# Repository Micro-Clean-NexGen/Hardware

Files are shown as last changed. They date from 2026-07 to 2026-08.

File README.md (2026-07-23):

## Hardware
This document describes the hardware architecture and operating principles of our robot's Mobility and Autonomous Navigation subsystem — the first subsystem being developed for the MVP. It covers locomotion, real-time localization, and obstacle detection and avoidance.

The Steam Cleaning, Air Treatment, along with the full Power Management and Electrical Architecture, will be documented later as development on those areas proceeds. This document follows the same format so all subsystem documents remain consistent and easy to compare.

This documentation covers: electrical wiring, power distribution, computing, sensors, motor control, the bill of materials, and safety notes.

Hardware documentation for the Autonomous Steam Cleaning & Air Sterilization Robot: electrical wiring, power distribution, computing, sensors, motor control, the bill of materials, and safety notes.

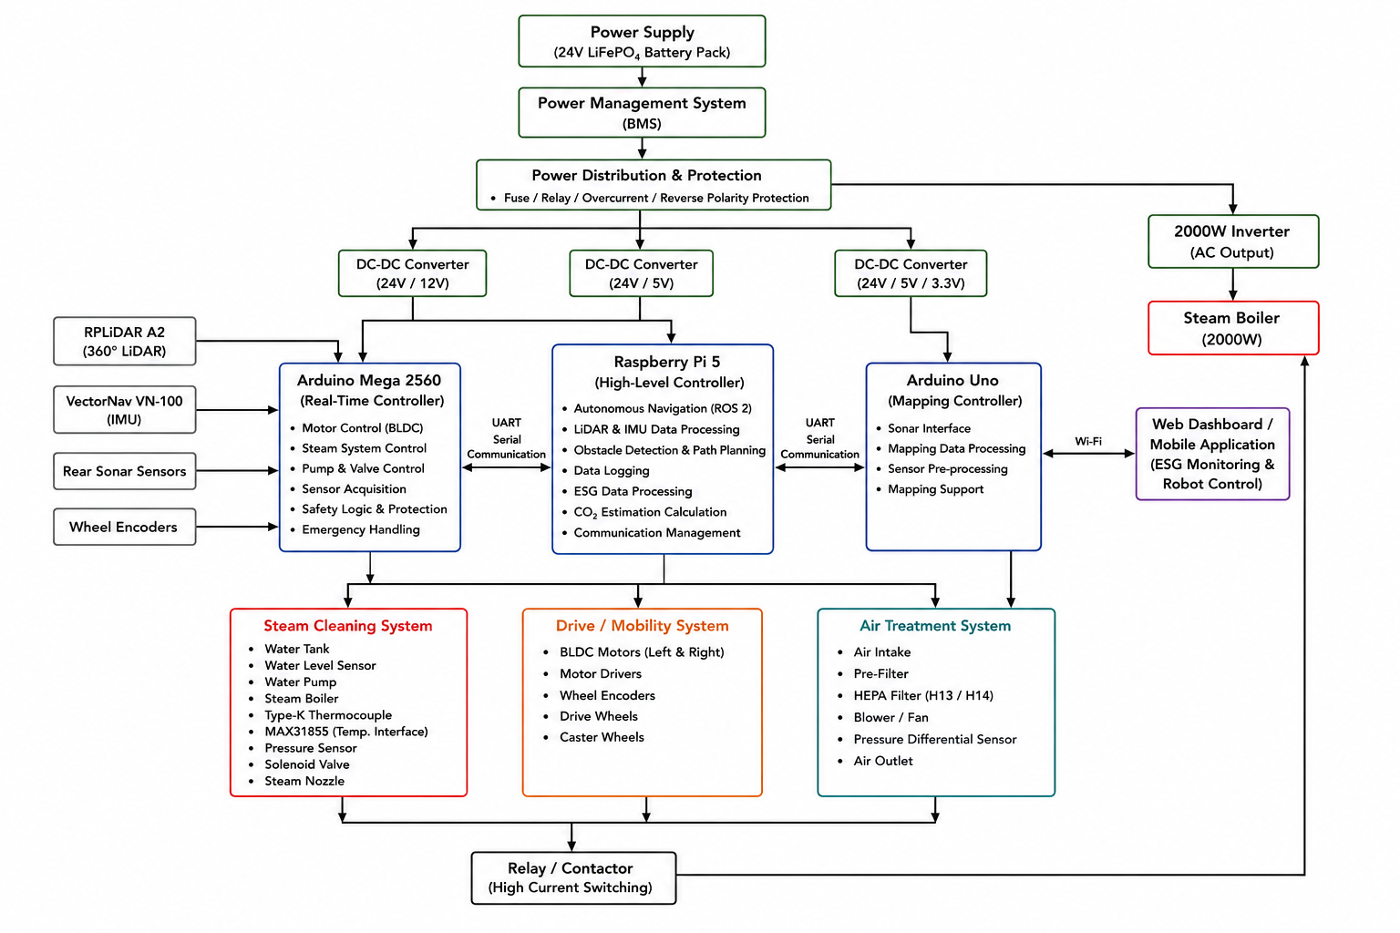
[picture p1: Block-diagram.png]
Block diagram of whole system


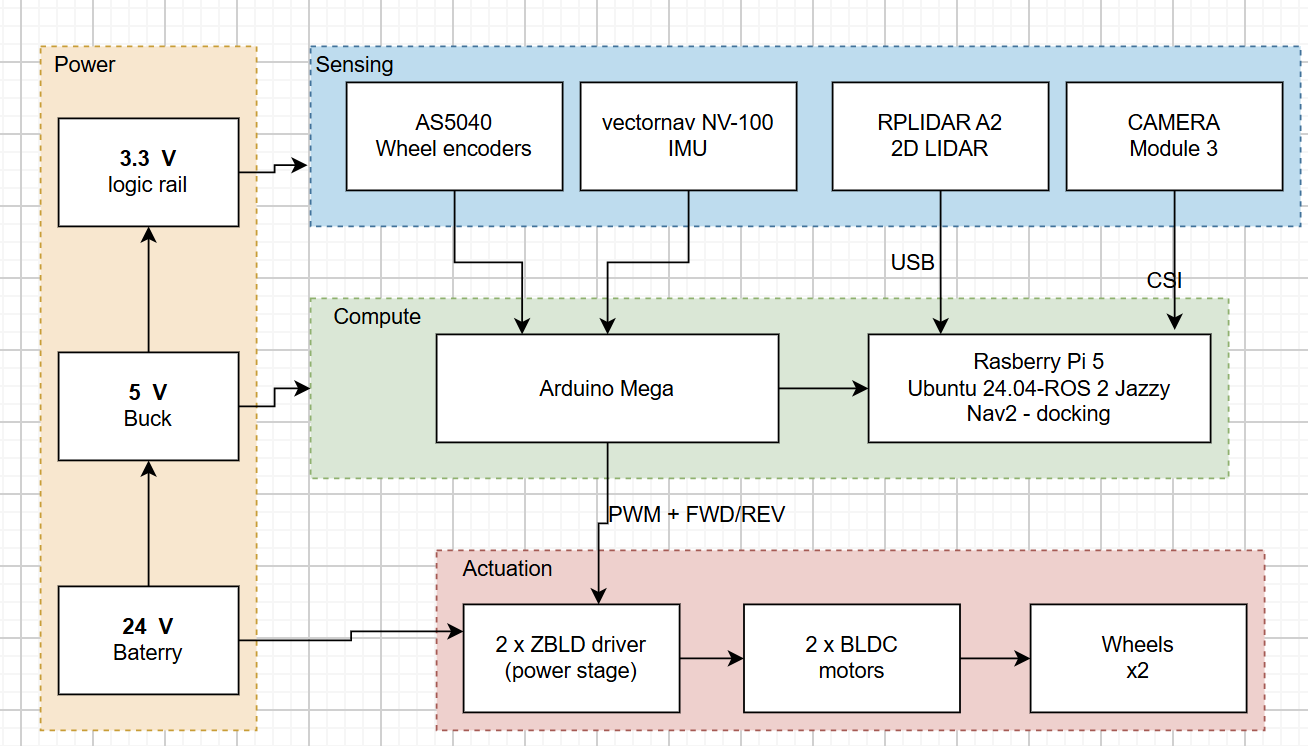
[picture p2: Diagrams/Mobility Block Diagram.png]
Block diagram of mobilty system


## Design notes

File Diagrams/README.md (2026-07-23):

## **Diagram folder used inside hardware repository**

**Battery and Charging space**
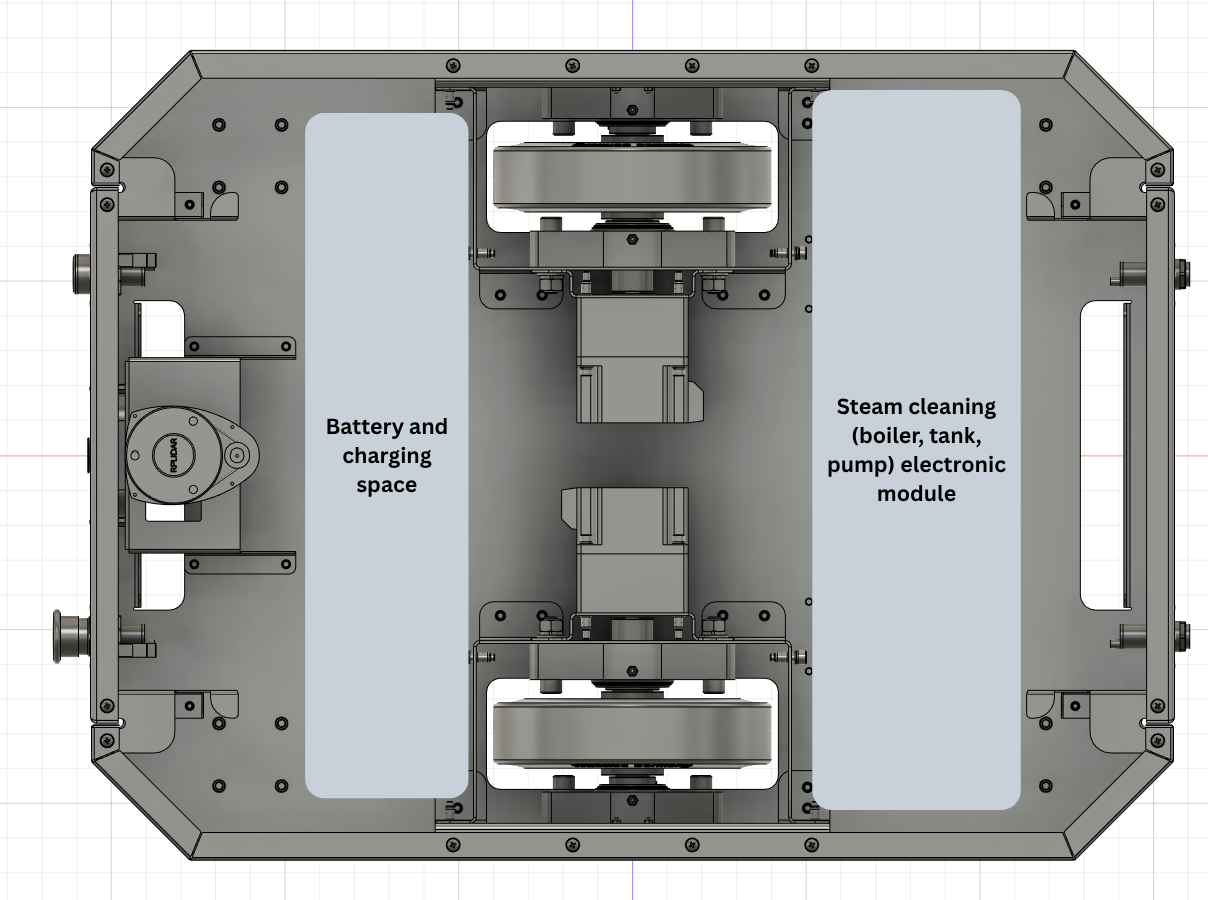
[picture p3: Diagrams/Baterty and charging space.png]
Battery and Charging Space


**Mobiltiy Block diagram**
Mobility Block Diagram

**Mobility Full Assembly**
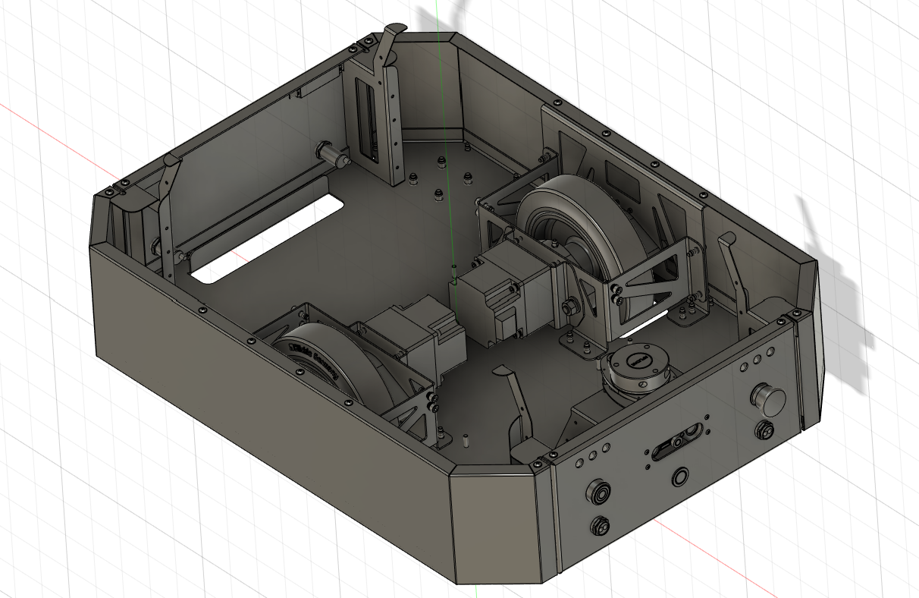
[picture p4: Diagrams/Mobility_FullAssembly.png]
Mobility Full Assembly


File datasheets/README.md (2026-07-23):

# Datasheets

Manufacturer datasheets and manuals for the components used on (or offered as options for) the
Autonomous Steam Cleaning & Air Sterilization Robot **base**. 

> ⚠️ **Third-party documents — copyright of their respective manufacturers.** These PDFs are
> **re-hosted for convenience** with attribution to the source (see each folder). They are **not**
> covered by this repository's licence; all rights remain with the manufacturers.

## What applies to the base build vs. what is optional

The base of the robot documented in this repo uses the **ZD** motor + driver. The **ZLTech** and
**TZBot** parts are **alternative / optional** components for larger product configurations
(higher-power drives, wireless charging, lift, larger battery) — they are **not** on the base build as in the current version for MVP.

| Component | On the base build? |
|---|---|
| ZD BLDC motor (Z4BLD60-24GN-30S) + **ZBLD.C20-120L2R** driver | ✅ **yes — this is the base** |
| ZLAC8015D / ZLAC8030L industrial drivers (CANopen/RS485) | ⚙️ option (higher-power variant) |
|  ZLLG80 hub-motor wheel | ⚙️ option (alternative drivetrain) |
| 24 V 20 Ah battery + BMS (serial protocol) | ⚙️ option (product battery/BMS) |
| WCM-300 wireless charger | ⚙️ option (auto-docking charge) |
| Lift reducer (TZDSXZ-48-400) | ⚙️ option (lift attachment) |

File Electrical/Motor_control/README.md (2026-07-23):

# Motors & drivers (BLDC + ZBLD)

*Last updated: 2026-07-22.*

## Overview
Two **BLDC** (brushless) motors, one per wheel, each driven by its own **ZBLD** driver. The Teensy
sends low-current logic signals to the drivers; the drivers deliver the 24 V power to the motor phases.

- **Motors**: **ZD Z4BLD60-24GN-30S** ×2 — 3-phase BLDC, 24 V, **60 W**, **P=5 (5 pole pairs, on the
  nameplate)**, **3000 rpm** motor + **1:25 spur gearbox** (4GN 25K) → **120 rpm** wheel, rated **3.8 A**.
  U/V/W + Hall. (LEFT=M1, RIGHT=M2) See the [sizing calculations](../../datasheets/motor-sizing-calculations.md).
- **Drivers**: **ZBLD.C20-120L2R** ×2 (24 V, 7.5 A, 120 W). Full specs + datasheets:
   **Red LED / fault blink codes:**
  [motor-driver-fault-codes.md](motor-driver-fault-codes.md).
- ⚠️ **Pole pairs = 5** → verify the driver **DIP SW4/SW5** are set to 5 pole pairs (read the silkscreen
  table on the driver). A wrong pole-pair setting throws off the driver's closed-loop speed scaling.

## Manufacturer reference diagram

The driver's full terminal layout, DIP-switch table, and LED status codes, from the manufacturer:

![ZBLD.C20-120L2R driver setup: 24 V DC+/DC- (fused), motor phases U/V/W + Hall sensors, control inputs FWD/DI1, REV/DI2, JOG/DI3, CLR/DI4, BRK/DI5, COM, VAR/AI2, +5V, ERR/DO1, SPD/DO2, RS485 A/B, the SW1-SW6 DIP-switch configuration table, and the LED status/fault codes]()

*Source: ZD **ZBLD.C20-120L2R** product manual (manufacturer reference figure). This robot wires only a
subset of these terminals and uses a specific DIP configuration — both are detailed below.*

## Communication (Teensy → driver)

The motor-control signal chain is shown below.

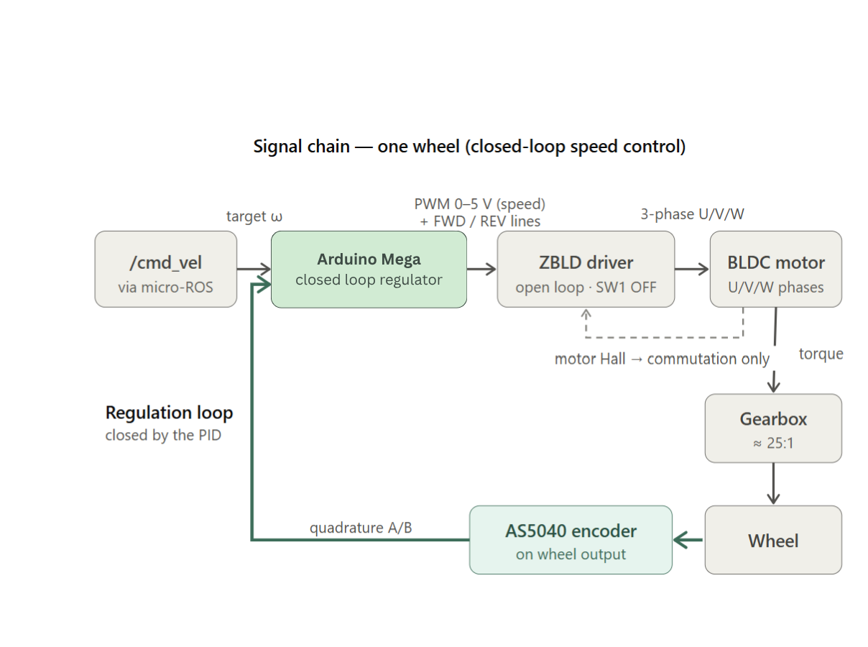
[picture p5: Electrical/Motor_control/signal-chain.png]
Figure — per-wheel signal chain: /cmd_vel → Teensy PID (closed loop) → ZBLD driver (open loop) → BLDC → 25:1 gearbox → wheel → AS5040 encoder back to the PID


Per motor, 3 logic lines from the Teensy:

| Arduino signal | Driver input | Meaning | Left pin | Right pin |
|---|---|---|---|---|
| PWM | `VAR / AI2` | speed setpoint — Teensy PWM @ **3 kHz** on this robot (driver capability: PWM 0–20 kHz, or analog 0–5 V) | **1** | **5** |
| IN_A | `FWD / DI1` | forward direction | **20** | **6** |
| IN_B | `REV / DI2` | reverse direction | **21** | **8** |
| GND | `COM` | **common ground (mandatory)** | GND | GND |

- Power side: `DC+ / DC− = 24 V` (with a fuse). Motor side: phases U/V/W + Hall.
- ⚠️ The driver `COM` **must** be tied to the Teensy GND, otherwise signals/encoders are noisy.

Of the driver's twelve control terminals, this robot wires only **four** — the connections are shown below:

Driver terminal wiring: only DI1 (FWD), DI2 (REV), COM (GND), and AI2 (VAR/PWM speed setpoint) go to the Teensy; DC+/DC- take the fused 24 V and U/V/W + Hall go to the motor

## Driver configuration — DIP switches (SW1–SW6)
Both drivers must be set **identically**. Functions read from the driver silkscreen (2026-06-19):

| Switch | Function | What it does | Was (pre 06-19) | **Now (applied 06-19)** |
|---|---|---|---|---|
| **SW1** | open / closed loop | ON = driver regulates speed itself from the Halls; OFF = driver is just a power stage (Teensy regulates) | ON | **OFF** |
| **SW2** | speed source (`AI1/AI2`) | OFF = internal VAR knob; ON = external 0–5 V on `VAR/AI2` (our Teensy PWM) | ON | ON |
| **SW3** | secondary (direction/internal) | no effect here (direction is driven by FWD/REV pins) | OFF | OFF |
| **SW4 / SW5** | **motor pole pairs** | tells the driver the pole-pair count (2/3/4/5) to convert Hall freq → RPM. **Only used in closed loop** | OFF/OFF (= 2 pp ⚠️) | **ON/ON (= 5 pp)** |
| **SW6** | RS485 termination | bus end resistor; not used (no RS485) | OFF | OFF |

> 🔶 **Pole-pair mismatch found & corrected (2026-06-19):** the motor is **P=5** (5 pole pairs, on the
> nameplate) but SW4/SW5 were OFF/OFF (= 2 pole pairs). Now set to **ON/ON (= 5 pp)**. (Only matters in
> closed loop; harmless but correct in the current open-loop config.)

### Which controller is best — driver vs Teensy PID?
The **Teensy PID is the better controller for this robot** and should be the authoritative one:
- it reads the **AS5040 encoder (1024 cnt/rev)** → fine resolution, and measures the **wheel** speed
  (post-gearbox) — the variable we actually care about (motion + odometry);
- it is **fully tunable** (K_P/K_I/K_D, already tuned to ±2 %), and feeds ROS `/odom`.
- the driver's loop measures the **motor shaft** (pre-gearbox) with **coarse Hall** sensors, is **opaque**
  (only VAR/ACC pots), and needs correct pole pairs.

→ **Run the driver open-loop (SW1=OFF)** so the Teensy is the sole regulator (removes the double-loop that
worsens snaking; makes pole pairs irrelevant). **Plan B** if low-speed cogging appears: go back to closed
loop (SW1=ON) **with SW4/SW5=ON/ON (5 pp)** for a proper cascade (fast driver inner loop + Teensy outer).
The only edge the driver loop has: at low *wheel* speed the motor shaft still spins ~30× faster → richer
Hall signal → potentially smoother very-low-speed than the 50 Hz Teensy loop.

**Config applied 2026-06-19 (both drivers):** `SW1 OFF · SW2 ON · SW3 OFF · SW4 ON · SW5 ON · SW6 OFF`.
(Was SW1 ON, SW2 ON, rest OFF.) **Validated** over 3 motor runs — see
the `openamr-platform-sw` troubleshooting doc (`docs/troubleshooting/diagnostics.md` in that repo).

> ⚠️ **VAR pot is inert in this config**: with SW2=ON the speed comes from AI2 (the PWM), not the VAR/AI1
> pot, so turning VAR does **not** balance the wheels (confirmed: no change across runs). The residual
> ~9 % open-loop L/R asymmetry (right faster) is corrected by the **Teensy PID** (→ ~0.2 % in closed loop).

## Driver configuration — TWO trim pots (CRITICAL)
Each driver has **two** potentiometers. **They must match between LEFT and RIGHT** (calibrate the right
to the left, the known-good reference).

> ⚠️ **Read this alongside the config state.** The VAR **gain** effect below (and the "runaway" root cause)
> applies when **VAR is in the speed path** — i.e. the *original* config (VAR/AI1 selected, or an AI2 gain
> that scales the PWM). In the **current config (SW1=OFF open loop, SW2=ON → AI2)** the **speed comes from
> the PWM on AI2, so the VAR pot is inert for balancing** (see the note above) — the values below are the
> setting to leave it at, not a live balancing knob. ACC/DEC still ramps in either config.

| Pot | Location | Function | Correct setting | Symptom if wrong (when VAR is in the speed path) |
|---|---|---|---|---|
| **VAR** | top | speed / gain (PWM → speed) | ~3.5/10, **same** both sides | too high → wheel runs ~8× too fast → **runaway** |
| **ACC/DEC** | near the DIP switches | acceleration/deceleration ramp | **4/10**, same both sides | =0 → no smoothing → **jerks/oscillation** in closed loop |

See the full story in the `openamr-platform-sw` troubleshooting doc (`docs/troubleshooting/diagnostics.md` in that repo).

## Low-speed behaviour — measured velocity floors (2026-07-02)
Closed-loop sweep **on the ground / under load** (`/cmd_vel` with the PID + dither, as in docking),
real velocity read on `/odom/unfiltered`:

| Axis | Stall | Judder | **Reliable floor** | Clean |
|---|---|---|---|---|
| **Linear** | ≤ 0.02 m/s | 0.03 (min 0, std 0.018) | **0.04 m/s** (min 0.020) | **0.05 m/s** (std 0.004); 0.06–0.10 perfect |
| **Angular** | ≤ 0.08 rad/s | 0.10–0.12 (min 0, high std) | **0.15 rad/s** (min 0.093) | 0.20–0.30 perfect |

> ✅ **The motor is WELL-SIZED (over-sized on torque).** Above the floors the real/commanded ratio is
> **~1.0** → no torque shortfall. The floors are **stick-slip (static friction) + coarse Hall commutation
> at low RPM** (an *operating-point* limit, not a sizing one). Reference: the Z4BLD60-24GN-30S + **1:25**
> gearbox gives a mechanical no-load max of ~**1.26 m/s** (software-capped to ~0.71 m/s) and ~**3.48 N·m/wheel**

**Consequence:** keep commanded velocities **above the floors**. Docking applies this (drive taper floored
at 0.05 m/s, scan rotation 0.17 rad/s, a `min_turn_omega` of 0.15 rad/s with a small deadband so
sub-floor yaw corrections are snapped up or zeroed rather than stalling). Judder on each start-from-standstill
is the static-friction breakaway; a taper (or the driver ACC/DEC ramp) mitigates it.

## Good to know / gotchas
- The original fault ("right wheel runs away, robot doesn't go straight") was **100 % driver tuning**, in
  the **original config where VAR was in the speed path**: the right VAR pot was at max (10) and its
  ACC/DEC pot at 0. After matching both pots to the left, the right wheel tracked correctly. *(Separately,
  during open-loop balancing on 2026-06-19, raising the right VAR made the right wheel speed up to match a
  faster left — same knob, opposite direction, because it was a different starting point.)*
- ⚠️ In the **current config (SW2=ON, AI2 source)** VAR no longer balances the wheels — the residual L/R
  asymmetry is handled entirely by the **Teensy PID** (the right channel needs slightly more PWM for the
  same speed; the PID compensates → ~0.2 % in closed loop). Do not chase balance with the VAR pot here.
- Test the motors safely with the **open-loop mode** (`/debug/openloop`) which bypasses the PID — useful
  to compare the two channels at identical PWM. See the `openamr-platform-fw` debug-telemetry doc (`docs/architecture/debug-telemetry.md`).
- **Always**: wheels off the ground, 24 V on, a hand on the 24 V cut-off for the first tests.

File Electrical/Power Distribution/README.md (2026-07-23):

# Power & electrical safety

*Last updated: 2026-07-23.*

## 🔋 Battery state of charge — THRESHOLDS — READ BEFORE ANY NAV TEST
The design takes **any 24 V battery** . The at-rest thresholds below are for the
**reference build's pack** 
(LiFePO4 / Li-ion rest at different voltages and have flatter discharge curves). **At-rest** voltage
(no load):

| At-rest voltage | State | For navigation |
|---|---|---|
| **~25.5–26 V** | full charge | ✅ OK to test |
| **~24.5 V** | ~70 % | ✅ acceptable |
| **~24 V** | ~50 % | ⚠️ marginal |
| **≤ 23.5 V** | discharged (~30 %) | ❌ **DO NOT test nav** |

⚠️ This is the **at-rest** voltage: **under load (motors) it drops further** (often −1 to −2 V at peaks,
since the pack sags). Below ~22 V under load → drivers undervoltage (ZBLD **fault code 10**, see
[motor-driver-fault-codes.md](../motor_control/motor-driver-fault-codes.md)) → **weak torque + left wheel
(loose contact) drops out → the robot does not follow the plan → it hits obstacles that nav was actually
avoiding.** **RULE: aim for ≥ 25 V at rest before any navigation/avoidance test.** Otherwise we debug Nav2
for nothing (already happened: the real problem was the 24 V, not nav).

**Reading 2026-06-20 (end of session)**: battery at **23.4 V at rest → too low**. Every avoidance test
from this session is inconclusive until the battery is recharged (~25.5 V). To be resumed after charging.

The power distribution is shown in the diagram below.

Figure — power distribution: 230 V charger, 24 V battery (with the missing fuse and disconnect), 24 V drivers, and the buck-derived 5 V/3.3 V logic

## Power architecture — VERIFIED 2026-06-19
```
Battery 24V ──┐
              ├──(parallel)──► V+ / V−  of BOTH drivers   (brown = V+, blue = V−)
Mains 24V  ───┘
              └──(parallel)──► DC-DC 24V→5V ──► Raspberry Pi ──USB──► Teensy ──► IMU + encoders (3.3V)
```
| Element | Supply |
|---|---|
| Motors / drivers | **24 V DC** on `V+ / V−` of each driver. Wire colors: **brown = V+, blue = V−** (confirmed) |
| 24 V source | a **24 V battery pack** (any chemistry) **or** an **AC/DC converter** (230 V mains) — wired **in parallel** to the same 24 V bus |
| Raspberry Pi | **DC-DC 24 V→5 V** buck from the 24 V bus |
| Teensy | powered over **USB** from the Pi (5 V) |
| **IMU + encoders** | **3.3 V from the Teensy** (3.3 V rail). The encoders were originally on the 5 V (VUSB) pin → ~4 V on the Teensy inputs → moved to 3.3 V on 2026-06-19; see ⚠️ encoder overvoltage in [encoders.md](../sensors/encoders.md). The IMU has always been on 3.3 V. |
| LiDAR | powered over its USB (CP2102 adapter) from the Pi |

## 🔴 Safety gaps found (2026-06-19) — to fix
1. **No fuse on the battery.** A 24 V battery can deliver **hundreds of amps** into a short → fire /
   burns / melted wires if a 24 V conductor touches ground. **Add a fuse (or breaker) on the battery `+`**,
   as close to the terminal as possible. Sizing: 2 motors × **3.8 A** nominal ≈ 7.6 A + the DC-DC → a
   **~15–20 A** fuse (above nominal, below the wire/battery limit). ⚠️ This is above *nominal*, not the
   *stall* current — a jammed motor draws well above 3.8 A, so a fast-blow at 15–20 A may nuisance-trip or a
   short one may not clear a stall instantly; confirm the motor stall current before finalising.
2. **No battery-side disconnect** (only the mains has a switch). No fast hardware cut-off for the 24 V
   battery. **Add a switch/disconnect — ideally an E-stop mushroom** — on the battery `+`.
3. **Battery AND mains in parallel** on the same bus: if both are ever connected **at once**, the stiffer
   source back-feeds the other (risk to the AC/DC, or uncontrolled battery charge). **Only one source at a
   time** — a source selector switch would make this safe.

## Battery pack

Any **24 V** battery works — the drivers and the buck only see the 24 V bus, not a chemistry. The
**reference build** uses:

- **4 × 12 V** batteries (lead-acid, the big black ones).
- Wired **2 in series → 24 V** (one "pair"). With 2 pairs you can make **24 V** (pairs in parallel, more
  capacity) **or 48 V** (pairs in series) — this matches the OpenAMR platform's "24/48 V" spec.
- **In practice we usually run a single pair = 24 V.**
- ⚠️ Battery care depends on the chemistry you choose. For the reference **lead-acid** pack: respect
  polarity, don't short the terminals (very high current), charge with a suitable lead-acid charger, and
  don't fully deep-discharge (shortens life). Other chemistries (LiFePO4/Li-ion) need their own BMS /
  charger and voltage limits.

The Teensy sends only **low-current logic signals** to the drivers; the **24 V power** goes through the
drivers to the motor phases. Logic ground (Teensy GND) and driver `COM` must be **common**.

## ⚠️ Electrical safety — 230 V AC (read this)
The 24 V side is low-risk, but the **AC/DC converter is fed by 230 V AC, which is potentially lethal.**

- Touching exposed 230 V can cause cardiac fibrillation, "can't-let-go" muscle tetany, burns. ~30 mA
  through the body is already dangerous.
- If the converter's mains terminals are exposed/unprotected, **treat it as dangerous** and let nobody
  touch it while powered.

**Minimum protections (in priority order):**
1. **30 mA RCD / residual-current device** upstream — the single most important life-saver (cuts power in
   milliseconds on a ground/body leak).
2. **Enclose all 230 V wiring** in a closed box — no bare mains conductor reachable by a finger.
3. **Earth** the converter's metal chassis (protective conductor).
4. **Fuse / breaker** on the mains input (short-circuit / overload).
5. **Strain relief** on the mains cable; prefer an IEC inlet over flying leads.
6. **Golden rule**: cut/unplug the mains **before** touching anything on the power side. Never work live.

## Battery vs mains — measured 2026-06-18 (battery sags under load)
Same motor step (0.25 m/s ≈ 24 rpm), comparing the PWM the PID needs to reach that speed:

| Supply | PWM needed for ~23 rpm |
|---|---|
| AC/DC mains (24 V stiff) | ~180–220 |
| Battery pack | **~290–349** (~60 % more) |

The battery read **24.4 V at rest** but needs **~60 % more PWM** under load → it **sags under load**
(weak/discharged pack or high internal/contact resistance). Not blocking now (PID compensates, PWM ≈ 34 %
of the 1023 max), but at higher speeds it will **plateau**, and a sagging 24 V rail is what made the
**left wheel drop out** when its cable also had a loose contact (see the `openamr-platform-sw` troubleshooting doc (`docs/troubleshooting/diagnostics.md` in that repo)).

**Practical rule:** keep the pack **charged**; if motors feel weak / one wheel drops, **check battery
voltage under load** (multimeter on the terminals while commanding) and the 24 V connectors before
suspecting the firmware/PID. Bench-test on mains for repeatable results.

## ⚠️ Pi 5 brown-out at bring-up — the 5 V rail must hold ≥ 5 A (2026-06-25)
The Raspberry Pi 5 needs **5 V / 5 A**. At bring-up, motors + LiDAR + camera start **at the same time** →
a **current spike on the 5 V rail** → if the DC-DC (or a sagging 24 V pack) can't hold it, the rail
collapses and the **Pi freezes (Ctrl-C dead) then loses the network** (no ping). At boot the Pi warns:
*"This power supply is not capable of supplying 5A; power to peripherals will be restricted."*

- **Symptoms** (a whole session, 2026-06-25): frozen terminal during a launch, SSH drops, `No route to
  host`, LiDAR stops, involuntary reboots. **Before blaming the software, check the Pi is still alive
  (`ping`).** This is a *power* failure, **not** the thermal throttling (that one keeps the Pi online — see
  [raspberry-pi.md "Thermal"](../computing/raspberry-pi.md)).
- **Cause = insufficient 5 V supply** (worse when the 24 V pack is low → the buck can't source the peak).
  No ROS/software setting fixes it.
- **Fixes:** battery **≥ 25 V** (thresholds above); a **5 V buck rated ≥ 5 A peak** with a short/thick
  cable; or the official 5 V/5 A supply for bench tests. **Confirmation test:** launch the bring-up
  **without the camera** (lighter load) — if it holds, it's the supply (the camera adds the fatal peak).
- Same root cause hits the **motor drivers**: a 24 V bus too low trips **fault code 10 (busbar
  under-voltage)** on both ZBLD drivers at once — see
  [motor-driver-fault-codes.md](../motor_control/motor-driver-fault-codes.md). Low battery is the common
  thread (Pi brown-out + drivers code 10 + soft torque).

## Stopping the robot quickly (test safety)
- Software: stop publishing `/cmd_vel` → firmware zeroes motors after 200 ms (watchdog). `Ctrl-C` on the
  publisher works too.
- Hardware backstop: keep a hand on the **24 V cut-off** during powered tests. Wheels off the ground.

## TODO / to document
- Charger model, AC/DC converter model, and whether a physical **E-stop** exists (a ROS-independent
  emergency stop is recommended). *(Battery capacity is known: DM12-7S = 12 V 7 Ah, a pair in series =
  24 V 7 Ah — see [components-bom.md](../../manufacturing/bom/components-bom.md). Fuse: ~15–20 A, see the
  safety gaps above.)*
- A **battery voltage monitor** would be useful (batteries sag under load; low voltage → erratic motors).

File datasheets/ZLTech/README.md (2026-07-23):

ZLTech components for advanced products.
Sz EXW preliminary price:
Wheel: ZLLG80ASM250-L V1.0 - 115USD/1pc
Driver: ZLAC8015D - 145USD/1pc

Contact:
Finkle: finkle@zlingkj.com
Melady: melady@zlingkj.com

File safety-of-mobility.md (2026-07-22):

# Safety

*Last updated: 2026-07-22.*

## Motor / movement tests
1. **Wheels off the ground** for all initial motor tests.
2. **24 V on** only when you need the wheels to turn; keep a **hand on the 24 V cut-off**.
3. **Low speeds** to start (the guide recommends max 0.05 m/s linear, 0.15 rad/s angular).
4. The firmware has a **200 ms command watchdog**: no `/cmd_vel` → motors stop. Don't rely on it alone.
5. Stop ways: `k` (teleop), `Ctrl-C` (publisher), or the 24 V cut-off.
6. A **ROS-independent physical E-stop** is recommended (not confirmed present yet)

## ⚠️ Electrical — 230 V AC
The AC/DC converter is fed by **220 V mains, which is potentially lethal.** If its terminals are exposed:
- **30 mA RCD** upstream (top priority life-saver),
- **enclose** all mains wiring, **earth** the chassis, **fuse** the input,
- **cut/unplug mains before touching** the power side — never work live.

## Software / firmware changes
- Don't flash a new firmware without knowing you can re-flash a working one (the Teensy can't be dumped;
  firmware source: see `openamr-platform-fw`).
- After any firmware/config change, **re-verify** encoder directions and a low-speed `/cmd_vel` before
  driving normally.

## Equipment
- ⚠️ Do **not** kill the LiDAR driver brutally mid-scan (it gets stuck → unplug/replug).
- Common ground: drivers' `COM` ↔ Teensy GND, always.

## Before autonomy (Nav2 / docking)
Do not enable SLAM/Nav2/docking until manual motion, encoder direction, odometry, and stopping behaviour
are all validated (per the bring-up guide's gates).

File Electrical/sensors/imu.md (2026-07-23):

# IMU (MPU6500)

*Last updated: 2026-07-21.*

## Overview
An inertial measurement unit (accelerometer + gyroscope) on the Arduino's I²C bus. Used to improve
heading (yaw) estimation for navigation.

| | |
|---|---|
| Chip | **vectornav NV-100 IMU** (3-axis accel + 3-axis gyro) |
| Bus | I²C, address **0x68** (AD0 = GND) |
| `WHO_AM_I` (reg 0x75) | **0x70** (an MPU6050 would return 0x68) |
| Magnetometer | none (MPU6500 has no mag; the vectornav NV-100 would) |

## Communication (I²C → Arduino MEGA) —

The I²C wiring is shown in the diagram below.

IMU breakout (board marked vectornav NV-100, actual silicon MPU6500, WHO_AM_I 0x70) on the Arduino I2C bus: SDA->18, SCL->19, 3.3 V from the Teensy 3V3 pin, AD0 left floating (addr 0x68 = board default), on-board pull-ups

- `SDA = pin 18`, `SCL = pin 19` (Arduino default `Wire`) — confirmed on the board.
- **Supply = 3.3 V** (measured), `AD0 = GND` → address **0x68**, `GND` common with the Teensy.
- The Teensy is the I²C master; the IMU answers at 0x68.
- The firmware reads acceleration and rotation rate; it publishes raw IMU on **`/imu/data_raw`**
  (`sensor_msgs/Imu`) plus **`/imu/mag`** (`sensor_msgs/MagneticField`, see the no-magnetometer note
  below). The **filtered `/imu/data`** is produced host-side (Madgwick/EKF), not by the firmware.
  *(Older revisions of this doc said the firmware publishes `/imu/data` directly — that is outdated;
  the deployed 2026-06-29 firmware publishes `/imu/data_raw` + `/imu/mag`.)*

> ✅ **No level-shift issue here** (unlike the encoders): the GY-521 board runs on **3.3 V**, so its
> on-board I²C pull-ups pull to 3.3 V → SDA/SCL never exceed 3.3 V → safe for the Teensy 4.0.
> Unused pins: `XCL`, `XDA` (auxiliary I²C), `INT` (data-ready interrupt).

## Firmware driver — the fix
The **vectornav NV-100** driver checks `WHO_AM_I == 0x68` and **rejects** our chip (which returns 0x70)
→ `setup()` used to hang (LED 3 blinks, no topics). The fix:

- Use **`USE_vectornav_NV-100_IMU`** in `lino_base_config.h` (instead of `USE_ectornav_NV-100_IMU`).
- The vectornav NV-100 driver accepts it: it reads `WHO_AM_I` bits [6:1]; `0x70` → `0x38`, which its
  `testConnection()` accepts (`NV-100.cpp`). The vectornav NV-100 is register-compatible with the vectornav NV-100 core
  (accel+gyro), so it works.

## Status (verified)
- ✅ `/imu/data_raw` publishes **real data**: at rest, `linear_acceleration.z ≈ 9.74 m/s²` (gravity).
- ⚠️ `/imu/mag` is published for message-shape compatibility only — the vectornav NV-100 has **no magnetometer**,
  so it carries no real magnetic field; do not fuse it as a heading source.
- The `linear_acceleration.x ≈ -2` at rest means the IMU is **mounted at a slight tilt** (to account for
  in the URDF later).

## Fusion in the EKF (done 2026-07-21)
The IMU is now fused by the `robot_localization` **EKF** (`~/ekf.yaml`) — but **only `angular_velocity.z`**
(yaw rate). Measured behaviour at rest (robot perfectly still): gyro X/Y/Z biases are tiny, and **gyro Z
reads ~0 with a firmware deadband** → no heading drift on straight lines. During an actual turn, gyro Z
**tracks the real rotation** closely (verified against wheel odometry, e.g. both ≈ −25 °/s while turning).
Conclusion: the gyro Z is healthy and the fusion mainly **reduces heading drift in turns** (where wheels
slip). The accelerometer is **not** used (tilted mount + only yaw matters in 2D). See
the `openamr-platform-sw` navigation/architecture docs.

> ⚠️ Measure the bias only when the robot is **strictly immobile** — moving it during the capture gives a
> bogus (even sign-flipping) bias reading.

## Good to know
- **No orientation**: the driver provides raw accel + gyro only; the orientation quaternion in
  `/imu/data_raw` is all zeros (invalid). For sensor fusion (EKF / `robot_localization`), use the
  **angular velocity** (`angular_velocity.z`, yaw rate), not the orientation.
- A tiny standalone I²C scanner project on the reference Pi (`~/i2cscan`) can re-check the bus /
  address (`WHO_AM_I`) if needed.
- The firmware default scales: accel ±2 g (`1/16384`), gyro ±250 °/s (`1/131`).

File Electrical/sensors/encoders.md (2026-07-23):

# Encoders (AS5040)

*Last updated: 2026-07-23.*

## Overview
Magnetic incremental encoders, one per wheel, that let the Teensy measure each wheel's rotation
(for speed feedback in the PID and for odometry).

| | |
|---|---|
| Type | AS5040 magnetic, quadrature A/B |
| Resolution | **1024 counts/rev** (`COUNTS_PER_REV` in firmware) |
| **Supply voltage** | **3.3 V** (from the Teensy 3.3 V rail; was 5 V until the 2026-06-19 fix) ⚠️ see hazard below |

> ✅ **RESOLVED 2026-06-19 — encoders moved to 3.3 V supply.** *History:* the encoders were powered at
> **5 V**, and the AS5040 A/B outputs (output level = supply) read **~4 V** at the Teensy pins. The Teensy
> 4.0 inputs (14/15/11/12) are **3.3 V, NOT 5 V tolerant** (abs. max ~3.6 V); the ~4 V meant the Teensy's
> clamp diode was conducting (out of spec, ages the pin).
> **Fix applied:** the AS5040 is rated 3.3–5 V (internal regulator), so its **supply was moved from the
> Teensy 5 V (VUSB) pin to the 3.3 V rail**. Verified: supply = 3.3 V, A/B lines now top out at **~3.3 V**
> (no more 4 V), and the encoders **count cleanly** (validated over 3 sustained motor runs — see
> the `openamr-platform-sw` troubleshooting doc (`docs/troubleshooting/diagnostics.md` in that repo)). The 5 V (VUSB) pin now feeds nothing (normal).
> *Alternative fixes if 3.3 V had browned out:* series R ~1–2.2 kΩ or a divider per A/B line, or a
> level-shifter. (The IMU is correctly on **3.3 V** 

## What is a "quadrature" encoder? (quick primer)
An encoder measures wheel rotation. This one outputs **two square-wave signals, A and B, shifted 90°
apart** — that 90° shift is the "quadrature". As the wheel turns:
```
forward:               reverse:
A ┌─┐ ┌─┐ ┌─┐          A ┌─┐ ┌─┐ ┌─┐
  ┘ └─┘ └─┘ └            ┘ └─┘ └─┘ └
B   ┌─┐ ┌─┐ ┌─┐       B ┌─┐ ┌─┐ ┌─┐
  ──┘ └─┘ └─┘            ┘ └─┘ └─┘ └
   (A leads B)            (B leads A)
```
- **Count the edges** of A and B → **position** (more rotation = more counts).
- **Which signal leads** (A-before-B vs B-before-A) → **direction**.
- It is **incremental** (relative counts, not an absolute angle).
- 1024 counts/rev, and counting all edges of both channels gives **×4** resolution.
- "Magnetic" (AS5040): a magnet on the shaft + a sensor chip that generates the A/B pulses.

### "Hall" vs "quadrature" — not a contradiction
- **Quadrature** = the *output signal type* (A/B, 90° apart).
- **Hall-effect** = the *sensing technology* (reading a magnetic field).
The AS5040 **senses magnetically (Hall-array)** and **outputs quadrature** — both terms apply.

⚠️ **Two different "Hall" on this robot, don't confuse them:**
1. **Wheel encoder (AS5040)**: Hall-based magnetic sensing → **quadrature A/B output** → read by the
   **Teensy** for odometry/PID. **1024 counts/rev.**
2. **BLDC motor commutation Hall sensors** (3 per motor) → read by the **ZBLD driver** to commutate the
   motor phases (this is what "driver closed loop" refers to). The Teensy never sees these.

What tells them apart: **1024 counts/rev**. Commutation Hall sensors are very coarse (a few transitions
per rev) — they could never give 1024. That resolution means a real incremental encoder (AS5040). And it
is functionally confirmed: the firmware decodes clean A/B quadrature and the counts increment correctly.

> ✅ **Confirmed 2026-06-19**: the chip marking reads **"AS5040 AB 2.2"** → it IS an AMS **AS5040**.
> Its default incremental output is **256 PPR → 1024 counts/rev** in quadrature, which matches

## Communication 

The encoder-to-Arduino wiring is shown below.

Figure — two AS5040 quadrature encoders on the 3.3 V rail: LEFT A/B to Teensy 14/15, RIGHT A/B to 11/12, common GND, with the quadrature-waveform inset (1024 counts/rev)

Two digital signals **A** and **B** in quadrature, read by the Arduino on **interrupt** pins. The phase
relationship between A and B gives direction; counting edges gives position.

| Encoder | A pin | B pin |
|---|---|---|
| LEFT (MOTOR1) | **14** | **15** |
| RIGHT (MOTOR2) | **11** | **12** |

In the firmware:
- `encoder.read()` → raw absolute count (int32).
- `encoder.getRPM()` → speed in RPM (from count delta / time).
- The sign is configured by `MOTOR1_ENCODER_INV` / `MOTOR2_ENCODER_INV` so that **forward = positive**.

## Status (verified)
- ✅ Both encoders count correctly (proven by hand-spin tests).
- ✅ Direction sign correct on both sides (forward → counts increase, measured speed positive).
- ✅ Under power they read real motion cleanly (no electrical glitch/dropout).

> 🔧 **Right encoder was MISALIGNED (found & fixed 2026-07-20).** The robot snaked ("drunk"). A constant-PWM
> open-loop test **on the ground** (PID + driver loop bypassed) showed the right wheel oscillating wildly
> (6–62 rpm) while the left was smooth — but it was smooth **in the air** → a load/vibration-dependent
> fault. Cause: the right **AS5040 magnet was off-center** → erratic counts under load → the PID reacted →
> snaking. **Re-centering the magnet fixed it.** (The AS5040 needs the diametric magnet well-centered over
> the chip; check the field-strength indicator if available.) See the `openamr-platform-sw` troubleshooting doc (`docs/troubleshooting/diagnostics.md` in that repo) §8.

So the encoders are **healthy** when properly aligned. Tools to check counts live (Ubuntu, Cyclone domain 0):
`scripts/encread.py` (angle by hand), `scripts/encpid.py` (per-wheel target/measured/error).

## Velocity-error profile — residual eccentricity (measured 2026-07-06)
Even with the magnets re-centred, a small **speed-independent** velocity ripple remains, characterised by
binning the corrected debug rpm (`/debug/left|right.y`) against encoder position at three speeds (120 / 180
/ 250) — the three curves **overlap**, i.e. it is a **geometric error (magnet eccentricity)**, not a
speed/PID effect:

These numbers are the **un-calibrated** ripple — measured with the firmware ripple table **not loaded**
(passthrough = 1.0). The `calib_rpm(…)` table is applied *before* the debug rpm is published, so with no
table loaded `/debug/left|right.y` is the raw residual:

| Wheel | Velocity error, table NOT loaded (per revolution) | After `align_enc_cal` (table loaded) |
|---|---|---|
| **LEFT** (M1) | **±~11 %** (0.91–1.13) — the known off-centre encoder (raw, pre-centering, was ±~40 %) | **±~4 %** |
| **RIGHT** (M2) | **±~6 %** (0.94–1.06) | **±~3.5 %** |

> ✅ **No odometry drift, either way.** The profile is normalized to **mean = 1.000 over a full
> revolution** → the error **averages out per revolution**, so position/odometry does **not** drift; it
> only produces **intra-revolution velocity ripple** (the low-speed left "oscillation"/judder feel). It
> does not block navigation.
>
> **Deployed fix = a hot-loaded correction table + a per-boot phase re-align.** The ripple *shape* is fixed
> (it's the magnet geometry), so it is captured once (`scripts/encoder_ref_table.json`) and pushed into the
> firmware at runtime via `/debug/enc_cal` (`Float32MultiArray`), where `calib_rpm(…)` applies it
> instantly. This brings **LEFT ±~40 %/±11 % → ±~4 %** and RIGHT to **±~3.5 %**, and it **survives
> reboot** because the table is re-aligned each boot.
>
> ⚠️ **Why the re-align is mandatory (the incremental-phase caveat):** the AS5040 is read *incrementally*,
> so its count zero lands at a random wheel angle at every Teensy power-cycle. A **static/compiled** table
> is therefore applied at the wrong angle and does not hold — that failure is real. The per-boot
> `scripts/align_enc_cal.py` (~8 s: short spin → correlate the live ripple against the reference → publish
> the table at the correct phase) **solves** it. **Run `align_enc_cal.py` after every Teensy power-cycle**
> (the table lives in Teensy RAM; a ROS relaunch does not reload it).
>
> A 512-count (half-revolution) angular velocity *filter* was **considered but rejected** — it cancels the
> ripple but adds ~0.6 s of lag to the PID feedback. (Firmware details:
> `openamr-platform-fw` Teensy 4.0 overlay — `firmware.ino` `calib_rpm`, `/debug/enc_cal`.)

## Good to know / gotchas
- ⚠️ **CPR vs wheel + gearbox (1:25)**: the motors are **geared 1:25** (Z4BLD60-24GN-30S + 4GN 25K). `COUNTS_PER_REV = 1024` must be **per wheel revolution**. The firmware runs at **wheel scale** (`MOTOR_MAX_RPM 80` ≈ the 120 rpm geared output; open-loop ~14 rpm at
20 % PWM), which means the AS5040 effectively reads **wheel-scale** (1024 cnt = 1 wheel rev — mounted on the output side / not multiplied by 30). Odometry is therefore *consistent*, but **verify physically**:
  drive exactly 1 m and compare `/odom`.
- Raw counts are visible live on `/debug/left` and `/debug/right` (field `z`). See
  the `openamr-platform-fw` debug-telemetry doc (`docs/architecture/debug-telemetry.md`).

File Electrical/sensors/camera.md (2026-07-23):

# Camera (Pi Camera Module 3 NoIR / IMX708)

*Last updated: 2026-07-23.*

> **Status: WORKING + CALIBRATED (2026-06-19).** The camera streams to ROS (`/camera/image_raw` +
> `/camera/camera_info`), and the intrinsics are now calibrated (checkerboard) → `camera_info` publishes
> real K + distortion. See "Intrinsic calibration" below.

## Overview
| | |
|---|---|
| Module | Raspberry Pi Camera Module 3 **NoIR** (Sony **IMX708** sensor, no IR-cut filter) |
| Autofocus | `dw9807` VCM (lens motor) on the module |
| Interface | **CSI** (MIPI ribbon to the Pi), **not USB** → handled by **libcamera** |
| Cabling | 15-pin FPC ribbon (Pi-4 style) → **CSI adapter (15→22-pin)** required for the Pi 5's narrower connector |
| Device | **"cam1"** on the Pi 5 CSI connector |

## Communication (Pi ↔ camera)
The connection is shown in the diagram below.

Pi Camera Module 3 NoIR (IMX708) -> 15-pin FPC ribbon -> CSI adapter (15->22-pin) -> Raspberry Pi 5 cam1 connector (CSI/MIPI, not USB; libcamera RPi fork)

- **CSI / MIPI** ribbon into the Pi's camera connector. Kernel side is fully OK:
  `camera_auto_detect=1` (in `/boot/firmware/config.txt`) loads the overlay; the media graph is
  `imx708_noir → csi2 → pisp-fe → rp1-cfe` (verify with `media-ctl -d /dev/media0 -p`).
- The capture is driven by **libcamera**, exposed to ROS by the **`camera_ros`** node.

## ⚠️ The libcamera gotcha (and the fix) — IMPORTANT
On **Pi 5 + Ubuntu 24.04 + ROS 2 Jazzy**, the **apt** packages
(`ros-jazzy-libcamera` / `ros-jazzy-camera-ros`) use **upstream libcamera**, which does **NOT** support
the Camera Module 3 (IMX708) on Pi 5. Symptom:
```
camera_node → "no cameras available"
# debug (LIBCAMERA_LOG_LEVELS=*:0): rpi/pisp pipeline → "Unable to acquire a CFE instance"
```
The hardware/kernel are fine — it's purely a libcamera version problem. **Only the Raspberry Pi fork of
libcamera supports the IMX708.**

On the Pi, in `~/camera_ws`:
```bash
# build deps (apt)
sudo apt install -y g++ cmake meson ninja-build pkg-config libboost-dev libgnutls28-dev openssl \
  libjpeg-dev libpng-dev libtiff-dev python3-yaml python3-ply pybind11-dev python3-colcon-meson \
  libglib2.0-dev libgstreamer-plugins-base1.0-dev libdrm-dev libevent-dev

mkdir -p ~/camera_ws/src && cd ~/camera_ws/src
git clone https://github.com/raspberrypi/libcamera.git        # the RPi FORK (key!)
git clone https://github.com/christianrauch/camera_ros.git

cd ~/camera_ws
source /opt/ros/jazzy/setup.bash
rosdep install --from-paths src --ignore-src -y
colcon build --packages-select libcamera camera_ros           # ~6-7 min on the Pi 5
```
This overlay **shadows** the apt libcamera without removing it (reversible: just don't source it).
Reference guide: <https://github.com/erykpawelek/libcamera_ros2_setup>.

## Run it
⚠️ **Use 1280×720 `bgr8`** — the intrinsic calibration was done at 1280×720, so `camera_info` is only
valid at that resolution (the bring-up runs 1280×720 for this reason; see "Intrinsic calibration"). Run a
lower resolution **only for an uncalibrated preview**.
```bash
source /opt/ros/jazzy/setup.bash
source ~/camera_ws/install/setup.bash          # MUST source the overlay (RPi libcamera + camera_ros)
# Calibrated capture (matches camera_info):
ros2 run camera_ros camera_node --ros-args \
  -p width:=1280 -p height:=720 -p format:=bgr8 -p frame_id:=camera_optical_frame \
  -p camera_info_url:=file:///home/<user>/camera_info.yaml \   # reference install: /home/botshare/...
  -p FrameDurationLimits:="[100000,100000]"     # ~10 fps (see Performance below)
# Uncalibrated preview only (lighter; camera_info will NOT match): -p width:=640 -p height:=480 -p format:=RGB888
```
It is also wired into the main bring-up (`openamr_real_bringup.launch.py`) — just source `~/camera_ws`
before launching. Verified working at both 1280×720 and 640×480 `bgr8` on `/camera/image_raw`
(1280×720 is the calibrated default).

## ROS interface 
| Topic | Type | Frame |
|---|---|---|
| `/camera/image_raw` | `sensor_msgs/msg/Image` (bgr8, 1280×720) | `camera_optical_frame` |
| `/camera/image_raw/compressed` | `sensor_msgs/msg/CompressedImage` | `camera_optical_frame` |
| `/camera/camera_info` | `sensor_msgs/msg/CameraInfo` | `camera_optical_frame` |

> ✅ `camera_info` is now **calibrated** (2026-06-19) — loaded via `camera_info_url` (see below).

## Intrinsic calibration (done 2026-06-19)
Calibrated with a **9×12-square (8×11 inner corners) checkerboard, 30 mm squares**, using
`camera_calibration cameracalibrator` on the Ubuntu PC (87 views). Result (1280×720):
`fx≈1415.7, fy≈1415.1, cx≈629.3, cy≈366.4`; distortion (plumb_bob) `[0.0038, 0.217, ~0, ~0, 0]`.
Saved to **`scripts/camera_info.yaml`** (repo) and **`~/camera_info.yaml`** (Pi); the bring-up loads it via
`camera_info_url:=file:///home/<user>/camera_info.yaml` (reference install: `/home/botshare/...`).

> ⚠️ **Resolution must match the calibration**: it was done at **1280×720**, so the camera now runs at
> **1280×720** in the bring-up (intrinsics are resolution-dependent, and the 16:9 mode crops the 4:3 sensor
> — not a simple scale of 640×480). To run at 640×480, **recalibrate** at that resolution.
> The `camera name ... does not match narrow_stereo` warning is harmless (the calibration still loads).

### How to recalibrate (the working recipe)
WiFi can't carry the raw image → republish the **compressed** stream to a **local** raw topic, then point
the calibrator at the local topic (two terminals on Ubuntu, Cyclone + domain 0):
```bash
# T1: compressed (over WiFi) -> local raw
ros2 run image_transport republish --ros-args -p in_transport:=compressed -p out_transport:=raw \
  -r in/compressed:=/camera/image_raw/compressed -r out:=/camera_local
# T2: calibrator on the LOCAL topic
ros2 run camera_calibration cameracalibrator --size 8x11 --square 0.030 --ros-args -r image:=/camera_local
```
Move the board to fill X/Y/Size/Skew → CALIBRATE → SAVE (writes `/tmp/calibrationdata.tar.gz`).

## Mounting (measured) & TF
Physical position relative to `base_link` (center of the wheel axle):
- **x ≈ 0.415 m** (8 cm in front of the LiDAR, which is at x=0.335)
- **y = 0** (centered)
- **z ≈ 0.12 m** relative to `base_link` (≈ 0.175 m above the ground)
- Orientation: facing forward (to refine).

The bring-up publishes two static TFs:
```
base_link → camera_link        (x=0.415, y=0, z=0.12)
camera_link → camera_optical_frame   (roll=-90°, yaw=-90°  → ROS optical convention: z fwd, x right, y down)
```
Images are published in `camera_optical_frame`.

## ⚠️ Performance & bandwidth (IMPORTANT — learned the hard way)
The **raw** image is huge: 1280×720×3 ≈ **2.76 MB/frame** (640×480 ≈ 0.92 MB). Subscribing to
`/camera/image_raw` **over WiFi saturates the link** → multi-second lag on EVERYTHING (the camera AND
`/scan`/`/map`, since they share the network). Symptom seen 2026-06-18: ~3 s lag in RViz the moment an
Image display on the raw topic was added.

Rules:
- **Never pull the RAW image across WiFi.** Keep raw **local on the Pi** (for on-board nav/vision).
- **Remote viewing = always the `compressed` (JPEG) topic** (~30× smaller, ~100 KB/frame).
- **Reduce at the source**: 640×480 + `FrameDurationLimits:=[100000,100000]` (~10 fps) is plenty for a
  preview and very light. Bump up only when actually needed (and only on-board).

## View it on the robot (headless Pi) — the easy way
The Pi has no GUI, so grab a snapshot to a file (the compressed topic is already JPEG → bytes written
as-is, no decoding):
```bash
source /opt/ros/jazzy/setup.bash && source ~/camera_ws/install/setup.bash
python3 ~/cam_snapshot.py            # writes ~/cam_snapshot.jpg  (script in repo scripts/cam_snapshot.py)
```

## View the stream (from the Ubuntu dev PC) — use COMPRESSED
```bash
export ROS_DOMAIN_ID=0 && source /opt/ros/jazzy/setup.bash
ros2 run rqt_image_view rqt_image_view
# in the GUI: topic = /camera/image_raw, then set the transport dropdown to "compressed"
```
Needs `ros-jazzy-rqt-image-view` + `ros-jazzy-image-transport-plugins` on Ubuntu (already installed).
Do **not** add a raw Image display in RViz over WiFi (it lags everything).

## TODO
1. ✅ **Calibrate** the camera — done 2026-07-20 (see "Intrinsic calibration" above).
2. **Camera mount orientation**: the image is rotated ~90° (camera mounted sideways) and possibly tilted
   (not parallel to the ground) → refine the **`camera_link` extrinsic TF** (roll/pitch/yaw) before docking.
3. Fine-tune autofocus (the `dw9807` AF control logs minor warnings; functional but to configure).

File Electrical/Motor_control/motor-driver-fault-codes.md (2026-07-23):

# Motor driver fault codes — ZBLD.C20-120L2R

*How to read the driver's LED blink code and the full fault-code table. Driver: **ZBLD.C20-120L2R**
(Ningbo Zhongda Leader / ZD), 24 V ±20 %, 7.5 A, 120 W. One per wheel (LEFT = M1, RIGHT = M2).*

*Last updated: 2026-07-22.*

> When a driver detects a fault it **STOPS the motor** and blinks an error code on its LEDs. So a red LED
> is not cosmetic — the motor will not turn until the fault is cleared, even though the Teensy keeps
> sending PWM (you can confirm the Teensy side is fine: `/debug/pwm` still shows the commanded value).

## Reading the LED blink code

Each driver has a **green** and a **red** indicator. On a fault they flash a repeating pattern:

```
ERROR CODE = (number of GREEN flashes × 5) + (number of RED flashes)
```

Count one full cycle: the **green** flashes first (each green = 5), then the **red** flashes (each red = 1),
then it repeats. **Count green and red separately** — do NOT add them into one running count.

> ⚠️ **The encoding is NOT a clean base-5 code, so `green×5 + red` can alias** (e.g. 1 green + 5 red and
> 2 green + 0 red both arithmetic to 10). Do not "carry" a 5th red into an extra green — read the *actual
> emitted pattern* the driver blinks. Below are the patterns **observed on this robot** (field-confirmed);
> for any code not seen here, read the pattern off the driver and cross-check the fault-code table.

| You see (emitted pattern) | Code | Meaning | Confirmed |
|---|---|---|---|
| **1 green, 5 red** | **10** | busbar under-voltage | ✅ seen on this robot (2026-06-26) |
| **2 green, 4 red** | **14** | locked rotor | ✅ seen on this robot (2026-07-01, wheel jammed on wall) |

*(Other codes in the fault-code table below are from the manufacturer manual and have not been observed
here — read the blink pattern off the driver, then look up the code. Green contributes 5 each, red 1 each,
but trust the pattern the driver actually shows, not a computed sum.)*

## Fault-code table

| Code | Fault | Typical cause |
|---|---|---|
| **1–6** | **Over-current** (during acceleration / deceleration / constant speed) | short on the motor phases, motor stalled/jammed, wrong wiring, current limit too low |
| **7–9** | **Over-voltage** (different operating phases) | supply > 28.8 V, or regenerative braking spikes (decel) with no bleed |
| **10** | **Busbar under-voltage** | **24 V too low**: flat/weak battery, voltage drop under load, supply can't hold the current spike at fast acceleration, or driver HW fault |
| **11** | **Motor overload** | motor drawing too much for too long (load too high, gearbox binding) |
| **12** | **Driver overload** | driver output beyond its rating (7.5 A / 120 W) |
| **13** | **Hall sensor error** | Hall connector loose/miswired/disconnected → driver can't commutate |
| **14** | **Locked rotor** | motor blocked / can't turn (mechanical jam, brake on) |
| **16** | **Driver over-temperature** | heatsink too hot — sustained high load / poor cooling |
| **19** | Current sense error | internal current-measurement fault |
| **27** | Data storage error | driver parameter/EEPROM error |
| **29** | Over-current feedback error | current-feedback path fault |
| **30** | **Lack of input phase** | a motor phase (U / V / W) is missing — phase wire disconnected |

## Clearing a fault
1. **Fix the cause first** (see the table — e.g. for code 10, recharge the battery to ≥ 25 V).
2. **Power-cycle the 24 V** (cut, wait a few seconds, restore). Faults **latch** until a power cycle.
3. The red LED should go out and the motor respond again.

## Most common on this robot — code 10 (under-voltage)
**Both drivers showing code 10 at once = a shared cause = the 24 V bus is too low** (they share one
battery). The ZBLD.C20 needs **24 V ±20 % (≈ 19.2–28.8 V)**; below that → under-voltage → both stop.
- Diagnosis: measure the battery at rest — if **< ~22 V** (let alone < 19 V), that's it.
- Fix: **charge to ≥ 25 V → power-cycle the 24 V → red LED off → wheels turn** (`ros2 topic pub --rate 15
  /debug/openloop geometry_msgs/msg/Vector3 "{x: 100.0}"` with the robot lifted).

## If it is NOT under-voltage (battery confirmed good)
- **Code 13 (Hall error) / 30 (missing phase)** → a motor connector is loose/disconnected (check the
  Hall and U/V/W wiring; brown = +, blue = − for power leads).
- **Code 1–6 (over-current) / 14 (locked rotor)** → the motor is jammed or shorted — check the wheel
  turns freely and the phase wiring isn't shorted.
- **Code 16 (over-temp)** → let it cool; reduce sustained load.

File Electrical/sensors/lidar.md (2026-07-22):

# LiDAR (RPLidar)

*Last updated: 2026-06-17.*

## Overview
A 360° 2D laser scanner used for mapping, localization and obstacle avoidance. It is connected to the
**Pi** (USB), **not** the Teensy.

| | |
|---|---|
| Family | Slamtec **RPLIDAR** (firmware 1.29, hardware rev 7, SDK 1.12) |
| USB adapter | Silicon Labs **CP2102** USB↔UART bridge (VID:PID `10c4:ea60`) |
| Output | `/scan` (`sensor_msgs/msg/LaserScan`), ~7 Hz |
| Range | 0.15 – 12 m, 360° (`angle` ≈ ±3.04 rad), increment ≈ 1.3° |

## Communication (Pi ↔ LiDAR)
The connection is shown in the diagram below.

RPLIDAR A1 -> USB cable -> Slamtec adapter STC-A0317-R03 (CP2102 bridge, 10c4:ea60) -> Raspberry Pi 5 USB (/dev/ttyUSB0)

- **Physical**: USB → `/dev/ttyUSB0`
  (stable: `/dev/serial/by-id/usb-Silicon_Labs_CP2102_USB_to_UART_Bridge_Controller_0001-if00-port0`).
- **Protocol**: Slamtec RPLIDAR serial protocol over UART, **115200 baud**, `Standard` scan mode.
- **Driver**: `rplidar_ros`, node `rplidar_composition`. Parameters used:
  ```
  serial_port: /dev/serial/by-id/usb-Silicon_Labs_CP2102_...-if00-port0
  serial_baudrate: 115200
  frame_id: lidar_link
  scan_mode: Standard
  ```
- Published frame: **`lidar_link`** (must match the URDF / static TF `base_link→lidar_link`).

## Mounting (measured)
TF `base_link→lidar_link` = **x=0.335 m, y=0, z=0.18 m, yaw=180° (π)**. The LiDAR is 33.5 cm in front of
the wheel axle, centered, and **mounted rotated 180°**: its 0° points to the **rear**; the robot's front
is the LiDAR's 180°. (Found empirically — an object placed in front shows up at ±180° in the LiDAR frame.)

The RPLIDAR (on its bracket, right in this top view) sits ahead of the central electronics bracket:

Top view of the base with the cover removed — the RPLIDAR on its bracket is visible ahead of the drive wheels and the central electronics bracket

## Field of view note
The robot's own frame/structure produces close returns in several directions (≈ ±20–50° and ±80–90° in
the LiDAR frame), not a clean rear block. → a **`scan_body_filter`** (provided in `openamrobot_nav2`)
must mask those self-returns to produce `/scan_filtered` for Nav2.

## Good to know / gotchas
- ⚠️ **Do not kill the driver brutally while it is scanning.** A hard SIGTERM leaves the LiDAR stuck
  (`Cannot start scan: 80008000`, then `operation time out`). To recover: **restart the node once**
  (a clean fresh start usually re-inits it); if that fails, **unplug/replug the USB**. Don't loop-respawn
  on a stuck device.
- The LiDAR also sometimes **stops publishing on its own** (node alive but `/scan` silent). A single node
  restart brings it back. Cause not yet pinned (possibly USB power / motor). To watch.
- The LiDAR motor spins up when the driver starts and stops when it stops cleanly.
- Exact model (A1/A2/…) not formally confirmed; `Standard` mode at 115200 works.

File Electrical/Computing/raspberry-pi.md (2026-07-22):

# Raspberry Pi 5 — main computer

*Last updated: 2026-07-06.*

## Role
The high-level "brain". Runs **ROS 2**, the micro-ROS agent (bridge to the Teensy), the USB/CSI
sensor drivers (LiDAR, camera), odometry, and later the navigation (Nav2/SLAM).

## Specifications
| | |
|---|---|
| Model | Raspberry Pi 5 Model B Rev 1.1 |
| CPU | 4× ARM Cortex-A76 **up to 2.4 GHz**, **aarch64 / ARM64** |
| RAM | **8 GB** (measured 2026-07-06: 6.4 GB free under the full stack — RAM is *not* a bottleneck) |
| Active cooler | **NONE fitted** ⚠️ → thermal throttling under the robot stack, see "Thermal" below |
| OS | Ubuntu Server **24.04 LTS** (Noble) |
| Kernel | 6.8.x-raspi |
| ROS | **ROS 2 Jazzy** (`/opt/ros/jazzy`) |
| Hostname | `BOTSHARE` *(reference installation — substitute your own)* |
| User | `botshare` *(reference installation)* (groups: `dialout`, `video`, `sudo`, …) |

> **Note (2026-07-06):** the current board is an **8 GB** Pi 5, fitted during a hardware swap on
> 2026-07-06 (the DHCP address moved to `172.17.17.64`; reach it by mDNS `botshare.local`, not a hard-coded
> IP). Earlier notes in this repo referenced a **4 GB** unit — that was the previous board.

## Communication
- **To the Teensy**: USB → `/dev/ttyACM0` (stable: `/dev/serial/by-id/usb-Teensyduino_USB_Serial_<serial>-if00` (reference unit: `...16778200-if00`)).
  The Pi hosts the **micro-ROS agent** that exposes the Teensy's topics. See the micro-ROS / networking
docs in [`openamr-platform-sw`](https://github.com/openAMRobot/openamr-platform-sw) (`docs/real_robot/`).
- **To the LiDAR**: USB → `/dev/ttyUSB0` (CP2102 UART bridge).
- **To the camera**: **CSI** (ribbon cable), not USB.
- **ROS internal**: DDS = **CycloneDDS** (rmw_cyclonedds_cpp, adopted 2026-06-18 for Nav2/docking).

## Important directories (reference installation — `/home/<user>`, here `/home/botshare`)
| Directory | Contents |
|---|---|
| `~/microros_ws` *(reference install)* | the **micro-ROS agent** workspace (do NOT delete; it is the Teensy↔ROS bridge) |
| `~/teensy_firmware` *(reference install)* | the Teensy **firmware source** (see `openamr-platform-fw`) |
| `~/openamr-platform-sw` | OpenAMR **navigation** stack (cloned, not built yet) |
| `~/openamr_hardware_bringup_guide` | provided bring-up guide (reference) |
| `~/openamr_real_bringup.launch.py` | the **real bring-up launch** (agent+lidar+odom+TF) |
| `~/*.py` (encoder_*, powered_*, openloop_*, …) | diagnostic scripts |

## Access
SSH from the dev PC. See the `openamr-platform-sw` real-robot run-book (`docs/real_robot/`).
ROS 2 is sourced automatically in an interactive shell (`~/.bashrc`).
Over a **non-interactive** SSH command you must source it manually:
```bash
source /opt/ros/jazzy/setup.bash && source ~/microros_ws/install/setup.bash   # reference install path
```

## ⚠️ Thermal — no active cooler → the Pi throttles navigation (2026-07-06)
The Pi 5 is fitted with **no fan / no active cooler**. Under the full robot stack it overheats and the
firmware **clock-limits the CPU**, which slows navigation planning/costmaps.

Measured live under load (2026-07-06):
- **83.4 °C** core temperature (`vcgencmd measure_temp`), approaching the 85 °C hard limit.
- **`vcgencmd get_throttled` = `0x80008`** → **soft thermal limit ACTIVELY engaged** (bit 3) **and**
  has-occurred (bit 19). **No under-voltage bits set** — the *power* rail is fine; this is purely heat.
- At 83 °C the Pi 5 caps its clock (~**2.1 GHz** vs the 2.4 GHz max) to stay under 85 °C → the Nav2
  planner/controller and costmap updates slow down. **It is not a software bug — the CPU is being
  clock-limited by heat.**

Contributing load (work navigation does not need): `dock_trigger.py` ~36 % + `camera_node` ~19 % +
`apriltag_gate.py` ~19 % of a core (~74 % total) → load ~5.2 on 4 cores.

**Mitigations:**
1. **Fit the official Raspberry Pi 5 Active Cooler** (~€5–10 clip-on heatsink+fan). It keeps the SoC
   ~50–60 °C under load and removes the throttling. *This is the real fix (cooler on order 2026-07-06).*
2. Meanwhile, run the **light bring-up** (`use_camera:=false use_docking:=false`) — kills those three
   processes (~74 % of a core freed), drops load well under 4, and lets the Pi cool. This is the right
   default on the current (guest) Wi-Fi anyway (no camera flood).

Monitor: `watch -n1 "vcgencmd measure_temp; vcgencmd get_throttled"`.
[`get_throttled` bit reference](https://www.raspberrypi.com/documentation/computers/os.html#get_throttled).

## Good to know / gotchas
- **8 GB of RAM** (6.4 GB free under the stack) — RAM is not the constraint; the **thermal cap above** is
  what limits sustained compute. Heavy builds (Nav2, micro-ROS) still build faster sequentially.
- Watch **temperature** (`vcgencmd measure_temp`) and **throttling / under-voltage**
  (`vcgencmd get_throttled` — see "Thermal" above; a `brownout` at bring-up is a *power* issue, see
  [power.md](../power_distribution/power.md)).
- Always use `/dev/serial/by-id/...` paths (`ttyACM0`/`ttyUSB0` numbers can change on reboot).

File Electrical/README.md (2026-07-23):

## Electrical Architecture of mobility 

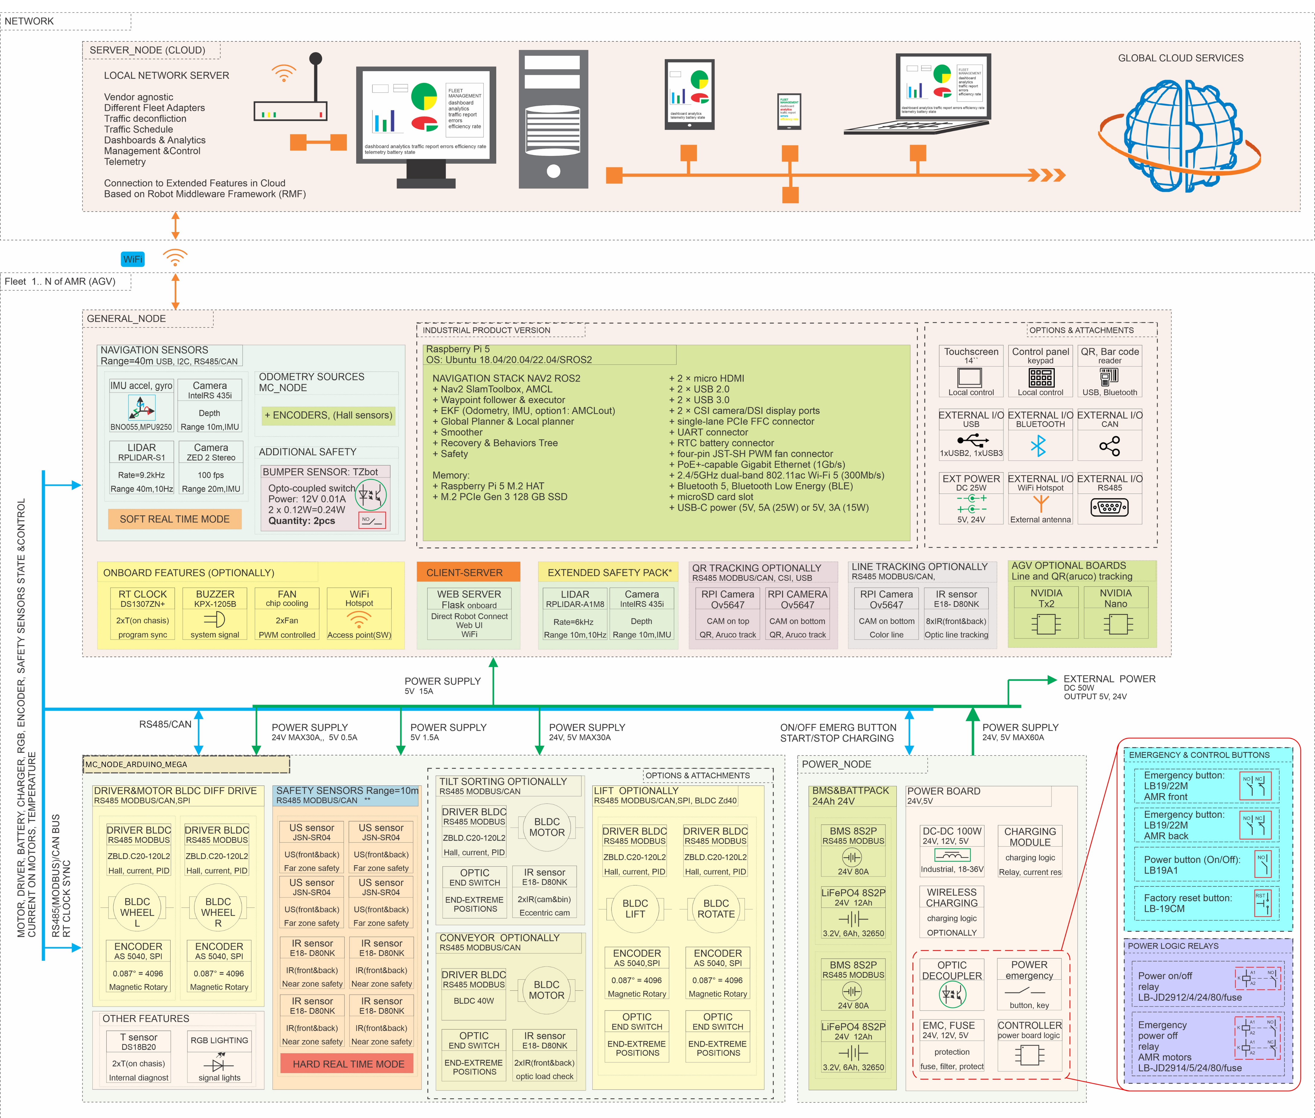
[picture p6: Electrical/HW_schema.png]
Hardware Architecture Diagram


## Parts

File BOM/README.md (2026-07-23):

# Components — Bill of Materials 

> **Two BOMs, by scope.** This file is the **electrical / electronic** BOM (compute, drivers, motors,
> sensors, power). The **mechanical** BOM — sheet-metal parts, fasteners, technological operations, and
> the Blickle wheel/castor — is [`mechanical-bom.md`](mechanical-bom.md) + the source workbook
> [`BOM_specs_MMP.xlsx`](BOM_specs_MMP.xlsx). Component datasheets are under [`../../datasheets/`](../../datasheets/).

| # | Component | Exact name / part number | Status | Datasheet / source |
|---|---|---|---|---|
| 1 | Microcontroller | **Teensy 4.0** (MCU NXP **i.MX RT1062**, Cortex-M7 600 MHz) | ✅ | [pjrc.com/store/teensy40](https://www.pjrc.com/store/teensy40.html) |
| 2 | Motor drivers ×2 | **ZBLD.C20-120L2R** (Ningbo Zhongda Leader / ZD) | ✅ | [manual V1.02 (PDF)](https://image.yhdfa.com/Uploads/Picture/PDF/FZ02_11/ZBLD.C20.pdf) · [product](https://www.zd-motor.com/product/ZBLD.C20-120L2R-64.html) |
| 3 | Motors ×2 | **Z4BLD60-24GN-30S** (ZD geared BLDC, 60 W / 24 V / 3.8 A / 3000 rpm / **P=5**) | ✅ nameplate | [analog F5B60-24GN-30S spec](https://www.omc-stepperonline.com/24v-60w-100rpm-geared-brushless-dc-motor-4-18nm-591-94oz-in-30-1-spur-gearbox-f5b60-24gn-30s-5gn30k) · [ZD](https://en.zd-motor.com/) |
| 4 | Encoders ×2 | **AMS AS5040** (magnetic, quadrature A/B, marking "AS5040 AB 2.2") | ✅ | [AS5040 datasheet (ams, PDF)](https://www.mouser.com/datasheet/2/588/AS5040_DS000374_4_00-2066720.pdf) |
| 5 | IMU | **TDK InvenSense MPU-6500** (board silk says "MPU-6050"/GY-521, but the chip is a 6500) | ✅ | MPU-6500 datasheet (TDK/InvenSense) |
| 6 | LiDAR | **Slamtec RPLIDAR A1** (A1M8, by shape) | ⏳ confirm sticker | [slamtec.com RPLIDAR A1](https://www.slamtec.com/en/Lidar/A1) |
| 7 | Camera | **Sony IMX708** = Raspberry Pi **Camera Module 3 NoIR** | ✅ | [raspberrypi.com camera-3](https://www.raspberrypi.com/products/camera-module-3/) |
| 8 | SBC | **Raspberry Pi 5** (Model B Rev 1.1, **8 GB** RAM — confirmed 2026-07-06 on the current board) | ✅ | [raspberrypi.com Pi 5](https://www.raspberrypi.com/products/raspberry-pi-5/) |
| 9 | DC-DC 24 V→5 V | generic **~300 W 20 A CC/CV buck** (toroid + 2 trimpots) | ⏳ no clear model | (generic) |
| 10 | Battery | **any 24 V pack** (chemistry up to you). Reference build: 4× **DM12-7S** 12 V **7 Ah** lead-acid (AGM), 2 in series → 24 V | ✅ | DM12-7S SLA datasheet (reference; any 24 V source works) |
| 11 | AC/DC 230→24 V | unknown | ⏳ read label | — |

## Key specs that affect configuration

### Motors — Z4BLD60-24GN-30S (ZD geared BLDC)
*Nameplate read 2026-06-19: 60 W, 24 VDC, 3000 RPM, 3.8 A, Class B Cont, IP20, **P=5**, dated 2021/07/11.*
- **3-phase, P=5 → 5 pole pairs** (confirmed on the nameplate), 24 V, **60 W**, rated current **3.8 A**.
- Motor **3000 rpm**, **spur gearbox 1:25** (gearbox **`4GN 25K`**, confirmed by the OpenAMRobot
  [sizing calculations](../../datasheets/motor-sizing-calculations.md) and the mechanical BOM) → **120 rpm
  at the wheel** (rated torque ~3.48 N·m at 25:1). ⚠️ The motor suffix **`-30S`** is a ZD series code,
  **not** the ratio — the gearbox is 4GN 25K = **25:1** (an earlier "~30:1" here was inferred from an
  analog part number and is superseded).
- **Hall sensors** for the driver's commutation (separate from the AS5040 encoder).
- ⚠️ **Pole pairs = 5** → the driver **DIP SW4/SW5** must be set for 5 pole pairs. **Set to ON/ON (= 5 pp)
  on 2026-06-19** (were OFF/OFF = 2 pp, wrong). A wrong pole-pair setting throws off the driver's
  closed-loop speed scaling (irrelevant in the current open-loop config, but set correctly). See
  [motors-drivers.md](../../electrical/motor_control/motors-drivers.md).
- ⚠️ **Gearbox 1:25** → odometry: `COUNTS_PER_REV = 1024` must be **per wheel revolution**.
  The firmware works at wheel scale (`MOTOR_MAX_RPM 80` = the configured cap, a modest headroom below
  the 120 rpm mechanical output; open-loop ~14 rpm at 20 % PWM), so the **AS5040 reads at wheel scale**
  (mounted on the output side / 1024 cnt = 1 wheel rev). **Still verify physically**: drive exactly 1 m,
  compare `/odom`.

### Drivetrain dimensions (for kinematics / odometry)
**Ground truth = the firmware config** (`lino_base_config.h`), physically measured:
- **Wheel diameter = 0.2 m** (radius 0.10 m).
- **Track (wheel separation) = 0.46 m** (`LR_WHEELS_DISTANCE`), **confirmed by tape-measure**
  (centre-to-centre of the two wheels). The CAD/URDF value of 0.4075 m is **wrong** (CAD artifact) —
  use 0.46 m; the sim `robot.sdf` still needs correcting (see the sim note below).
- With the firmware cap (`MOTOR_MAX_RPM 80` × `MAX_RPM_RATIO 0.85` = 68 rpm) → **max linear ≈ 0.71 m/s**
  (mechanical no-load ≈ **1.26 m/s** at the full **120 rpm** output — see the
  [sizing calculations](../../datasheets/motor-sizing-calculations.md)); rated torque **~3.48 N·m/wheel** (25:1).
  Reliable low-speed floors (measured on the ground): **linear 0.04–0.05 m/s, angular 0.15 rad/s** — see
  [motors-drivers.md](../../electrical/motor_control/motors-drivers.md) "measured velocity floors".

> ⚠️ **Do NOT use 0.046533 m as the wheel radius.** Earlier revisions of this BOM listed a wheel radius
> of 0.046533 m (⌀ 0.093 m) "measured on the real robot" — that was **wrong**. `0.046533` is the wheel
> **axle height (Z)** in the CAD-exported URDF, mis-propagated into the Gazebo `robot.sdf` diff-drive
> `wheel_radius` and copied here by mistake. The physical wheel is ⌀ 0.2 m (firmware, measured).
>
> **Latent simulation bug (openamr-platform-sw):** `robot.sdf` uses `wheel_radius 0.046533` /
> `wheel_separation 0.4075` while the wheel's own visual/collision cylinder is `radius 0.11` — so sim
> odometry/kinematics are scaled ~2× vs the visible model. Fix in `openamrobot_description`:
> set the diff-drive `wheel_radius` to 0.10 and `wheel_separation` to 0.46.

### Drivers — ZBLD.C20-120L2R
- **24 V ±20 %**, output **7.5 A**, **120 W**, open/closed loop (±0.5 %), ACC/DEC 0.3–10 s, 5 DI (NPN) / 2 DO.
- Speed command: internal knob (**VAR/AI1**), external **analog 0–5/10 V**, or **PWM 0–20 kHz** → on this
  robot the Teensy PWM goes to **VAR/AI2** (SW2=ON selects AI2). See [wiring-pinout.md](../../electrical/wiring/wiring-pinout.md).

### Encoders — AMS AS5040
- 10-bit magnetic; **default incremental = 256 PPR → 1024 counts/rev** in quadrature = `COUNTS_PER_REV`. ✅
- Supply **4.5–5.5 V**, but an **internal regulator allows 3.3 V operation**. **Output high level = supply
  voltage** → powered at 5 V it drove **5 V** on A/B (measured ~4 V overvoltage into the non-5 V-tolerant
  Teensy 4.0). **Fix APPLIED 2026-06-19:** supply moved to the **3.3 V** rail → 3.3 V outputs → safe.
  (Alternatives had it browned out: series R / divider / level-shifter.) See
  [encoders.md](../../electrical/sensors/encoders.md).

### Battery — 24 V (reference: DM12-7S)
- The design takes **any 24 V battery**. Reference build: **12 V, 7 Ah** sealed lead-acid (AGM), a pair
  in series = **24 V 7 Ah**. Any 24 V chemistry (LiFePO4 / Li-ion) works too — mind its own BMS/charger
  and adjust the voltage thresholds in [power.md](../../electrical/power_distribution/power.md). Batteries
  sag under load. ⚠️ No fuse / no disconnect currently — see the safety gaps in [power.md](../../electrical/power_distribution/power.md).
  Fuse sizing: 2 motors × **3.8 A** (nameplate) ≈ 7.6 A nominal + DC-DC → a **~15–20 A** fuse (above
  nominal, below the wire/battery limit). ⚠️ This is above *nominal*, not the *stall* current (a jammed
  motor draws well above 3.8 A) — confirm the stall current before finalising.

## Still to read off the robot
- **LiDAR**: confirm the model sticker (A1M8 vs other).
- **DC-DC buck**: any printed model / the regulator IC.
- **AC/DC 230→24 V converter**: brand + model + rating.
- **Gearbox**: ~~confirm the ratio~~ — **done: `4GN 25K` = 1:25** (matches the OpenAMRobot sizing calcs).

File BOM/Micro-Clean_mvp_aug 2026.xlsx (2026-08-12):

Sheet: Finance
Procurement List
Description | HKD | Date | Recipt - Hyper link
Arduino Circuit | 159 | 2026-07-25
Raspbarry5I with camara | 2600 | 2026-07-28
RP lider A2 | 1754 | 2026-07-28

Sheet: Supplier
Questions to send with every supplier inquiry What voltage does this operate at? (24V / 48V / 72V / 220V AC) What is the rated power? (W) What is the maximum continuous water flow rate? (L/min) What is the maximum outlet/operating temperature? Does it have dry-run protection? Is the wetted material SS304 or SS316? Is it rated for continuous-duty operation? What is the MOQ and sample lead time?
Reject on sight 220V AC-only units Heaters above 1500W (unless you're intentionally testing higher power) Domestic "heater + built-in booster pump" combo units — these are AC/domestic-use and don't give independent control over flow and pressure
 | supplier | link | details
1. Flow-Through Heater (Instant / Coil Heater) | tsheater | https://www.tsheater.com/industrial-heaters/tubular-heater/electric-water-heater-coil.html# | coil heater
 |  |  | Foshan-based coil makers — 1688/Made-in-China: "不锈钢瞬热管" (stainless steel instant heating tube) or "12V 24V 48V电热管."
2. Water Pump (DC Diaphragm Pump) | BODENFLO | https://bodenpump.com/ | high-flow miniature pumps design, R&D, manufacturing, sales, and service of DC mini pumps.
 | dyxpump | https://www.dyxpump.com/ | precision fluid-control mini air pumps, mini vacuum pumps,mini water pumps and solenoid valves,
 | Dongguan Shenpeng Electronics
3. Temperature Sensor | Shenzhen Testeck Technology Co., Ltd | https://www.made-in-china.com/showroom/testeck2016/
 | Shenzhen Senstech and Shenzhen Huachenkang
4. Solenoid Valve | Meishuo | https://www.meishuo-relay.com/solenoid-valves/ | Solenoid Valves Manufacturer
5. Water Tank |  | https://www.chunkerowaterplant.com/product/sus-304316-sterile-water-storage-tanks | water storage tanks
6. battery
7. cleaning autonomous robots vacuum based |  | https://robotinfo.dev/

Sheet: target spec sheet steam module
What boiler wattage (W) is in the steam cleaner you're buying? What battery voltage are you planning (24V, 48V, or 72V)? How many hours of runtime do you need between charges?
Steam module Archittecture
 | System-level architecture: 48V DC, battery-fed, no AC inverter stage. Target runtime: 60–90 minutes between charge/dock cycles. Approach: components sourced independently
1. Flow-Through Heater (Instant / Coil Heater) | 48V DC — the heater's input power/control voltage. This is the one that ripples out to everything else (battery, pump, valve) since you want the whole water path on one consistent voltage rather than mixing 24V and 220V AC components. 500–1000W — the heater's power rating. This is the number that drives your battery sizing. 0.3–1.0 L/min — this is really a heater-and-pump-together number. It's the flow rate the heater is rated to bring up to temperature at that wattage — if you push more water through than the heater can handle, it comes out lukewarm; less, and you waste power. So when you spec the heater, you size the pump to match this same flow window, not independently. <100°C outlet temp — the heater's max output temperature spec. Dry-run protection — a safety feature built into the heater itself (a sensor/cutoff that shuts off power if no water is flowing through the coil, so it doesn't overheat and burn out). SS304/316 wetted parts — this one applies to anything touching the water, not just the heater: the heater coil, the pump's internal diaphragm/housing, and the tank. Ask about material on all three, not just the heater.
 | 48V DC architecture, 500–1000W flow-through heater, 0.3–1.0 L/min flow rate, <100°C outlet temp, dry-run protection, SS304/316 wetted parts.
 | Spec | Target
 | Voltage | 48V DC
 | Power | 500–1000W
 | Max outlet temp | <100°C (target 80–100°C)
 | Flow rate rating | 0.3–1.0 L/min
 | Wetted material | Stainless steel 304 or 316
 | Dry-run protection | Required (built-in)
 | Duty cycle | Continuous
 | Form factor | Coil / flow-through block — not a tank/boiler
2. Water Pump (DC Diaphragm Pump) | Spec | Target
 | Voltage | 24V or 48V DC (match heater if possible)
 | Flow rate | 0.3–1.0 L/min (must match heater rating)
 | Type | Diaphragm, self-priming
 | Wetted material | SS304/316 or food-grade plastic rated for hot water
 | Max pressure | Only what the steam bar/nozzle design needs — low pressure (target 1–4 bar)
3. Temperature Sensor | Spec | Target
 | Type | PT100 or NTC
 | Range | Ambient to 110°C+ (headroom above the 100°C target)
 | Mounting | Inline probe, sized to your water line diameter
 | Output | Compatible with your controller (e.g. MAX31865 breakout for PT100)
4. Solenoid Valve | Spec | Target
 | Voltage | 24V or 48V DC
 | Type | Normally closed, water-rated
 | Wetted material | SS304/316 or compatible plastic
 | Port size | Match your tubing/hose diameter
5. Water Tank | Spec | Target
 | Material | Stainless steel (304/316) or food-grade plastic
 | Capacity | TBD once flow rate × target runtime and the other specs are locked
 | Mounting | Must fit the robot chassis footprint — need to confirm dimensions before ordering
baterry | to be decided later

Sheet: brainstorm ideas and plan
Component / Expense | Commercial AI Cleaning Robot (e.g., Commercial units) | Consumer AI Steam Robot (e.g., Samsung / Roborock style)
Upfront Purchase Price | $23,800 – $27,500 | $1,000 – $1,500
Alternative Leasing (RaaS) | $450 – $1,200 per month | N/A (Consumer retail model)
Edge AI Hardware (NPU/Chips) | $300 – $800 of total build | $50 – $150 of total build
Navigation & Vision Sensors | $2,000 – $4,000 (Multi-LiDAR + Depth Vision) | $150 – $300 (LiDAR + 3D Cameras)
Steam/Heating & Mechanicals | $8,000 – $12,000 (Heavy-duty boilers/scrubbers) | $200 – $400
Ongoing Maintenance / Pads | $1,500 – $3,000 per year | $50 – $150 per year
 | The heating and mechanical systems of a commercial AI cleaning robot cost $8,000 to $12,000 because they use industrial-grade boilers, heavy-duty brush motors, and high-pressure water delivery systems built to run up to 8 hours daily. [1] Unlike small home vacuums, these machines utilize ruggedized, high-voltage mechanical parts to blast away stubborn stains, grease, and grime in large public spaces. ## Cost and Technical Breakdown## 1. Steam Generation & Heating Assembly * * Estimated Cost: $2,500 – $3,500 * Core Hardware: Flash-heating boilers, high-pressure steam pumps, thermal insulation, and armored heating elements. * How it Works: The robot pumps water through a compact, high-efficiency boiler that heats up within seconds. It vaporizes water into pressurized steam exceeding 100°C to instantly sanitize floors and break down oils. * ## 2. Heavy-Duty Scrubbing & Agitation Mechanics * * Estimated Cost: $2,000 – $3,000 * Core Hardware: Dual cylindrical roller brushes, high-torque brushless DC (BLDC) motors, and heavy down-force tension springs. * How it Works: The AI system controls the brush motors to dynamically adjust the scrubbing pressure (down-force) from 15kg to over 40kg depending on the floor type and stain severity detected by the sensors. [2] * ## 3. Fluid Management & Squeegee Systems * * Estimated Cost: $1,500 – $2,500 * Core Hardware: Separate clean/dirty water tanks (often 15L to 30L capacity), high-vacuum suction motors, and self-leveling rubber squeegees. [3] * How it Works: After steam breaks down dirt, the vacuum motor pulls the wastewater off the floor via the squeegee. The AI monitors tank fluid levels to prevent overflow and optimize water usage. * ## 4. Automated Docking & Internal Self-Cleaning [4] * * Estimated Cost: $2,000 – $3,000 * Core Hardware: I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
 | Instead of a whole steam cleaner, source separately: Stainless steel heating coil Flow-through heater Small water pump Solenoid valve Temperature sensors Water tank
 | Before spending months integrating hardware: Buy instant heater. Build manual test rig. Steam + oscillating pad. Test on: marble porcelain tile polished granite Compare against: normal mopping scrubber machine
 | 1) Buy robot cleaner platform + source instant-heating components separately. 48V DC heating element (500-1000W) Stainless steel flow-through heater block Small diaphragm pump Temperature sensor (PT100 / NTC) Solenoid valve Water tank Insulation material Then connect it to: Existing autonomous cleaning robot chassis Wide steam distribution bar Oscillating microfiber pad | My gut feeling is that your biggest breakthrough opportunity is not AI or navigation. It's finding the minimum heater power that still delivers acceptable cleaning performance on marble and tile floors. If you crack that, your battery size, robot weight, and BOM cost all become much more competitive.
 | Your key insight is correct: mall floor cleaning does not require 180°C and 12 bar steam. That single assumption can reduce battery size, robot weight, safety risks, and BOM cost dramatically. The more you optimize for "just enough thermal cleaning" rather than "industrial steam cleaning," the stronger your MVP economics become.
 | What I Would Buy For an MVP robot: Independent diaphragm pump (24V or 48V DC) Independent flow-through heater (24V or 48V DC) Temperature sensor Solenoid valve Architecture: Water Tank ↓ DC Diaphragm Pump ↓ Flow Sensor ↓ Instant Heater ↓ Wide Steam Bar ↓ Oscillating Pad This gives your engineers full control of: flow rate temperature pressure steam output power consumption Very Important
 | Voltage? (24V, 48V, 72V, or 220V AC) Heater power? (500W, 800W, 1000W, 1500W) Maximum water flow (L/min) Maximum outlet temperature Dry-run protection? Stainless steel 304 or 316? Continuous-duty operation? For your application, I'd target approximately: 48V DC 500-1000W heater 0.3-1.0 L/min flow rate <100°C outlet temperature

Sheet: Core Components_july26 archived
Autonomous Steam Cleaning & Air Sterilization Robot MVP
Mobile base + shared boiler + dual subsystems (Steam Surface Cleaning + Air Sterilization). Onboard power, navigation, and autonomous path planning for indoor zones.
 | Item | Exact Part Number | Notes | Qty | unit price in HKD | Total price | Status | link | actual price
Compute & Control | Rasberry Pi | Raspberry Pi 5 (Model B Rev 1.1, 8 GB RAM | locomotion reads and processes sensor data build a map of room plan path, figure out its location on the map SLAM, localization, path planning, real time control | 1 | 2000 | 2000 |  | pindou dou order | 2600
 | Arduino Mega | Arduino Mega 2560 Rev3 | for steam control | 1 | 160 | 160 | ✅ | bought from Sham sui po | 159
 | IMU | vectornav NV-100 MPU 6050 | For Navigation; Mounted at center of wheel axis, fused via EKF | 2 | 120 | 240 |  | https://www.digikey.hk/en/products/detail/ceva-technologies-inc/BNO085/9445940
 | Sonar sensors | HC-SR04 | Waterproof, mounted rear of cover, both sides | 2 | 25 | 50 |  | taobao
 | Camera | Raspberry Pi Camera Module / Arducam IMX219 | 2D laser scanner for SLAM and obstacle detection (USB) | 1 | 20 | 20 |  | pindou dou order with rasberry pi 5
 | LiDAR | RPLIDAR A2 | Vision sensor for docking and computer vision tasks (CSI interface) | 1 | 1600 | 1600 |  | tao bao
Power System | battery | 24V 40Ah Li-ion / LiFePO4 pack | Main power source for motors and electronics | 1 | 4000 | 4000 |  | https://www.aliexpress.com/item/1005009744289146.html?curPageLogUid=pNvxQOzD2u9C
 | inverter | 2000W DC--> AC | Powers steam boilers + systems | 1 | 700 | 700
 | DC-DC Converter | LM2596 Buck Converter (24V → 5V, ≥5A) | Power supply for Raspberry Pi | 1 | 40 | 40
 | DC-DC Converter | DROK 24V → 5V/12V Step-Down Module | Power supply for sensors and auxiliary electronics | 1 | 200 | 200
 | Protection | Inline fuse (rated above motor current) | Overcurrent protection on main power line | 1 | 100 | 100
 | Safety E-stop switch' | Emergency stop switch | Manual power cutoff for safety | 1 | 100 | 100
mechanical | frame | N/A | laser cutting | 1
 | base plate | N/A | laser cuttinga & 3d printing | 1
 | DC drive motors | Z4BLD60-24GN-30S (ZD geared BLDC, 60 W / 24 V / 3.8 A / 3000 rpm / P=5) | 12V or 24V brushed DC, ~50-100W each for traction | 2 | 152 | 304 |  | https://www.omc-stepperonline.com/24v-60w-100rpm-geared-brushless-dc-motor-4-18nm-591-94oz-in-30-1-spur-gearbox-f5b60-24gn-30s-5gn30k https://www.robotshop.com/collections/brushless-dc-gear-motors
 | Drive Wheels(0.2 diamater) + tires frame | wheel radius 0.2 | Sized for motor torque; matching pair for differential drive | 2 | 150 | 300 |  | https://www.aliexpress.com/item/1005012385046827.html?curPageLogUid=tT6pZrpOarf9
 | Motor encoder sensors | AMS AS5040 (magnetic, quadrature A/B, marking "AS5040 AB 2.2") | Odometry feedback for each drive wheel | 2 | 20 | 40 |  | motor with encoder https://makerspet.com/product/n20-encoder-motor-12v-200rpm/ https://www.soundwell.hk/products/encoders/incremental-encoder https://hken.rs-online.com/web/c/passive-components/rotary-encoders/?pn=22
 | Motor driver | ZBLD.C20-120L2R (Ningbo Zhongda Leader / ZD) LM298N | Dual-channel PWM control for left/right drive motors 12779 stepper driver | 2 | 150 | 300 |  | get it from sham sui po store
 | Caster wheel | generic | Balance/pivot wheels at front or rear | 4 | 64 | 128
AEROSOL STERILIZATION | Aerosol nozzle/atomizer head | 1/4JN-SS+SU11-SS (Spraying Systems Co.) | Fine mist spray; can be fixed or rotatable | 1 | 50 | 50
 | HEPA filter cartridge (H13/H14) | Size-dependent — no universal PN. Reference grade: H13 per EN 1822 | 2× cartridges for redundancy or rotation | 2 | 150 | 300
 | Blower motor (12V/24V brushless) | RBM7530B1 (Pelonis Technologies, RB7530 Series DC Centrifugal Blower) | Air circulation; lower noise than brushed | 2 | 200 | 400
 | MOSFET driver for fan | IR2104SPBF (Infineon Technologies) | Switch fan on/off from Arduino GPIO | 1 | 50 | 50
 | Pressure differential sensor | SDP810-500PA (Sensirion AG) | Detect HEPA clogging | 1 | 200 | 200
 | Solenoid shutoff valve (aerosol) | Bürkert Type 7011 | Control steam to aerosol nozzle | 2 | 200 | 400
 | Flexible steam hose + fittings | 3D printing | Connect boiler to aerosol nozzle | 2 | 400 | 800
Steam Generation | Boiler | Generic | 10 bar pressure, built in thermostate, thermal fuse, insulated casing | 1 | 1500 | 1500
 | Water Tank | 0.5 L capacity, with water level indicator/sensor | 0.5L for the mvp | 1 | 100 | 100
 | Water Pump | Generic | Peristaltic, 30 mL/min discharge rate | 1 | 200 | 200
 | Check valve | Generic | Non-return valve; does not flow back | 1 | 50 | 50
 | Water tubing | Generic | flow of water | 1 |  | 0
 | water level sensor | TE Connectivity VS801-5 | measure water level | 2 | 60 | 120
Steam distribution | Steam hose | Synthetic braid flexible butyl rubber, rated ~6 bar / ~165 °C | 3d printed | 1 | 100 | 100
 | Nozzle | 3d printed | Heat-resistant nylon bracket, custom twin-arm design (2 slits, 2 mm height, 4 mm nozzle opening) | 1
 | Thermocouples+ MAX31855 breakout | Generic | Range 600 °C, | 2 | 200 | 400
 | TOF sensor | Generic | 4–30cm range (e.g. VL53L0X-class), floor-facing | 1 | 100 | 100
 | linear actuator | Roboclaw Motor | Mounted on middle-layer base plate | 1 | 200 | 200
 | actuator motor control/ dual channel motor controller | Sabertooth 2X12 Roboclaw motor controller | optimized for dual independent linear actuators | 1 | 650 | 650
 |  |  |  |  | Total | 15902

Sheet: List of fasteners
№ | Description | Q-ty, pcs
1 | Screw М4x16 DIN 912 | 8
2 | Screw М5x20 DIN 912 | 40
3 | Screw М5x70 DIN 912 | 8
4 | Screw М6x20 DIN 912 | 16
5 | Screw М10x45 DIN 912 | 8
6 | Screw М3x12 DIN 965 | 4
7 | Screw М3x8 DIN 966 | 4
8 | Screw М3x12 DIN 967 | 4
9 | Screw М4x12 DIN 967 | 36
10 | Screw М4x16 DIN 967 | 10
11 | Screw М8x25 DIN 967 | 4
12 | Screw М2x8 DIN 7985 | 8
13 | Screw М2x16 DIN 7985 | 4
14 | Screw М2,5x6 DIN 7985 | 4
15 | Screw М3x8 DIN 7985 | 10
16 | Screw М4x16 DIN 7985 | 4
17 | Nut M2 DIN 934 | 12
18 | Nut M3 DIN 934 | 14
19 | Nut M10 DIN 934 | 8
20 | Blind Rivet Nut - Round Thin - Stainless Steel - M4 | 58
21 | Blind Rivet Nut - Round Thin - Stainless Steel - M5 | 48
22 | Blind Rivet Nut - Round Thin - Stainless Steel - M6 | 16
23 | Blind Rivet Nut - Round Thin - Stainless Steel - M8 | 8
24 | Blind rivet Al/St 4,0х8, DIN 7337 | 16
25 | Washer 2 DIN 125 | 4
26 | Washer 2,5 DIN 125 | 4
27 | Washer 3 DIN 125 | 36
28 | Washer 4 DIN 125 | 4
29 | Washer 5 DIN 125 | 48
30 | Washer 6 DIN 125 | 16
31 | Washer 8 DIN 125 | 4
32 | Washer 10 DIN 125 | 12
33 | Spring lock washer 2 DIN 7980 | 4
34 | Spring lock washer 2,5 DIN 7980 | 4
35 | Spring lock washer 3 DIN 7980 | 10
36 | Spring lock washer 4 DIN 7980 | 12
37 | Spring lock washer 5 DIN 7980 | 32
38 | Spring lock washer 6 DIN 7980 | 16
39 | Spring lock washer 10 DIN 7980 | 8
40 | Large size washer 4 DIN 9021 | 8
41 | Feather key 4x4x25 DIN 6885-UNI 6604 (former ISO 773) | 2
42 | Feather key 8x7x28 DIN 6885-UNI 6604 (former ISO 773) | 2

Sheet: Application of fasteners with 3
№ | Description | Q-ty, pcs | 3D PDF | Blind Rivet Nut - Round Thin - Stainless Steel - M4 | Blind Rivet Nut - Round Thin - Stainless Steel - M5 | Blind Rivet Nut - Round Thin - Stainless Steel - M6 | Blind Rivet Nut - Round Thin - Stainless Steel - M8 | Blind rivet Al/St 4,0х8, DIN 7337 | Screw М4x16 DIN 912 | Screw М5x20 DIN 912 | Screw М5x70 DIN 912 | Screw М6x20 DIN 912 | Screw М10x45 DIN 912 | Screw М3x12 DIN 965 | Screw М3x8 DIN 966 | Screw М3x12 DIN 967 | Screw М4x12 DIN 967 | Screw М4x16 DIN 967 | Screw М8x25 DIN 967 | Screw М2x8 DIN 7985 | Screw М2x16 DIN 7985 | Screw М2,5x6 DIN 7985 | Screw М3x8 DIN 7985 | Screw М4x16 DIN 7985 | Nut M2 DIN 934 | Nut M3 DIN 934 | Nut M10 DIN 934 | Washer 2 DIN 125 | Washer 2,5 DIN 125 | Washer 3 DIN 125 | Washer 4 DIN 125 | Washer 5 DIN 125 | Washer 6 DIN 125 | Washer 8 DIN 125 | Washer 10 DIN 125 | Spring lock washer 2 DIN 7980 | Spring lock washer 2,5 DIN 7980 | Spring lock washer 3 DIN 7980 | Spring lock washer 4 DIN 7980 | Spring lock washer 5 DIN 7980 | Spring lock washer 6 DIN 7980 | Spring lock washer 10 DIN 7980 | Large size washer 4 DIN 9021 | Screwed spacer sleeve TFF-M3/25 | Feather key 4x4x25 DIN 6885-UNI 6604 (former ISO 773) | Feather key 8x7x28 DIN 6885-UNI 6604 (former ISO 773)
1.1 | Camera to Front panel |  |  |  |  |  |  |  |  |  |  |  |  |  | 4 | 4 |  |  |  |  | 4 |  |  |  | 4 |  |  | 4 |  | 16 |  |  |  |  |  | 4 |  |  |  |  |  |  |  | 4
1.2 | Cover to Center bracket |  |  |  |  |  |  |  |  |  |  |  |  |  |  |  |  |  | 4 |  |  |  |  |  |  |  |  |  |  |  |  |  |  | 4
1.3 | Lidar to support assembly |  |  |  |  |  |  |  |  |  |  |  |  |  |  |  |  |  |  |  |  | 4 |  |  |  |  |  |  | 4 |  |  |  |  |  |  |  | 4
1.4 | Lidar support assembly to base |  |  |  |  |  |  |  |  |  |  |  |  |  |  |  |  |  |  |  |  |  |  | 4 |  |  |  |  |  |  | 4 |  |  |  |  |  |  |  | 4
1.5 | Center bracket to base |  |  |  |  |  |  |  |  | 16 |  |  |  |  |  |  |  |  |  |  |  |  |  |  |  |  |  |  |  |  |  | 16 |  |  |  |  |  |  |  | 16
1.6 | Side panels |  |  |  |  |  |  |  |  |  |  |  |  |  |  |  | 32
1.7 | Front panel - up |  |  |  |  |  |  |  |  |  |  |  |  |  |  |  | 4
1.8 | Front panel - down |  |  |  |  |  |  |  |  |  |  |  |  |  |  |  |  | 10
1.9 | Support assemblies to base |  |  |  |  |  |  |  | 8 |  |  |  |  |  |  |  |  |  |  |  |  |  |  |  |  |  |  |  |  |  |  |  |  |  |  |  |  |  | 8 |  |  |  | 8
1.1 | Light duty swivel castors to base |  |  |  |  |  |  |  |  |  |  | 16 |  |  |  |  |  |  |  |  |  |  |  |  |  |  |  |  |  |  |  |  | 16 |  |  |  |  |  |  |  | 16
1.11 | Wheel assemblies to base |  |  |  |  |  |  |  |  | 16 |  |  |  |  |  |  |  |  |  |  |  |  |  |  |  |  |  |  |  |  |  | 16 |  |  |  |  |  |  |  | 16
2 | Cover assembly | 1 |  |  |  |  |  |  |  |  |  |  |  |  |  |  |  |  |  |  |  |  | 10 |  |  | 10 |  |  |  | 20 |  |  |  |  |  |  |  | 10
3 | Base assembly | 1 |  | 26 |  | 16
4 | Wheel assembly | 2 |  | 8 | 40 |  |  |  |  | 8 | 8 |  | 8 | 4 |  |  |  |  |  |  |  |  |  |  |  | 4 | 8 |  |  |  |  | 16 |  |  | 12 |  |  |  |  |  |  | 8 |  |  | 2 | 2
4.1 | Magnetic encoder | 2 |  |  |  |  |  |  |  |  |  |  |  |  |  |  |  |  |  | 8 |  |  |  |  | 8
6 | Center bracket assembly | 1 |  |  | 8 |  | 8 | 16
7 | Support assembly | 2 |  | 10
8 | Support assembly | 2 |  | 10
9 | Lidar support assembly | 1 |  | 4
 | Total: |  |  | 58 | 48 | 16 | 8 | 16 | 8 | 40 | 8 | 16 | 8 | 4 | 4 | 4 | 36 | 10 | 4 | 8 | 4 | 4 | 10 | 4 | 12 | 14 | 8 | 4 | 4 | 36 | 4 | 48 | 16 | 4 | 12 | 4 | 4 | 10 | 12 | 32 | 16 | 8 | 8 | 4 | 2 | 2

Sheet: Assembly Nuance
№ | Description
1 | Sheet metal parts vary by production. Currently, the parts are designed for the following coefficients and radii: K=0.47: sheet 0.8 mm - R=1.2; sheet 1.2 mm - R=1.5; sheet 2.0 mm - R=2.4.
2 | After bending, parts could be painted.
3 | After painting, we install riveting nuts. It is allowed to install riveting nuts before painting, provided that the threaded part of the nuts is protected from coating.
4 | Screws installed without lock washers - fix with a thread lock (eg Loxeal 55-03).
5 | There may be nuances with block bearings. All details are strongly interconnected and depend on each other.

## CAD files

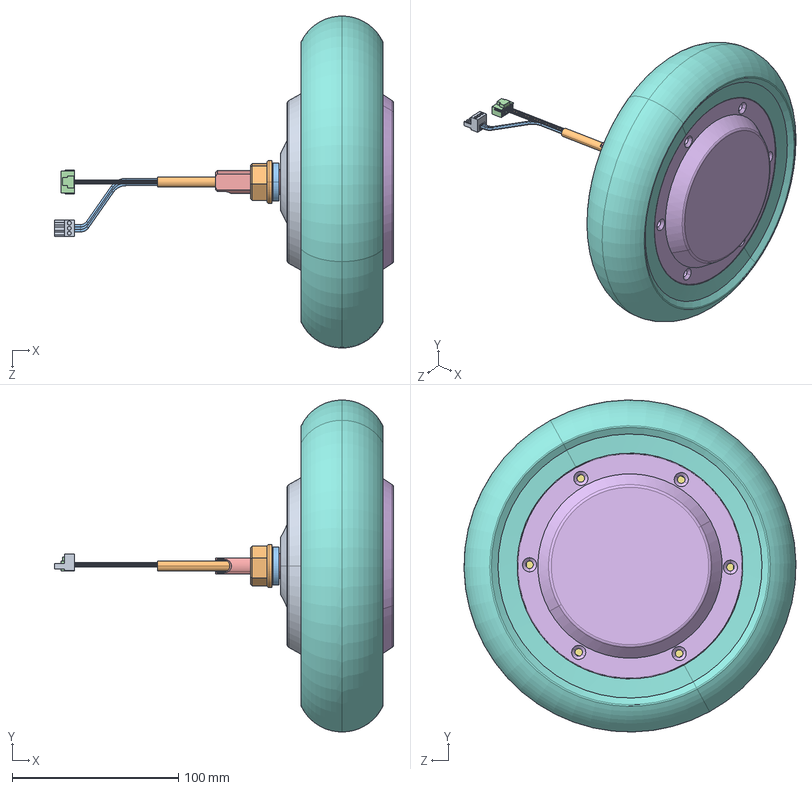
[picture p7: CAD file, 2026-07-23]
datasheets/ZLTech/wheel_ZLLG80ASM250/ZLLG80ASM250-L V3.0single-shaft.STEP
204.4 x 200.0 x 200.0 mm
5cun-1.1.stp
5G-shuang_1.1.stp
錨璃1.1.2.stp
錨璃1.stp
6.5C-QDG-KaiMo.stp
錨璃1.1.stp
錨璃2.1.1.stp
MANIFOLD_SOLID_BREP_6700.stp
ﾁ羮1.1.2.1.stp
Part1.2.stp

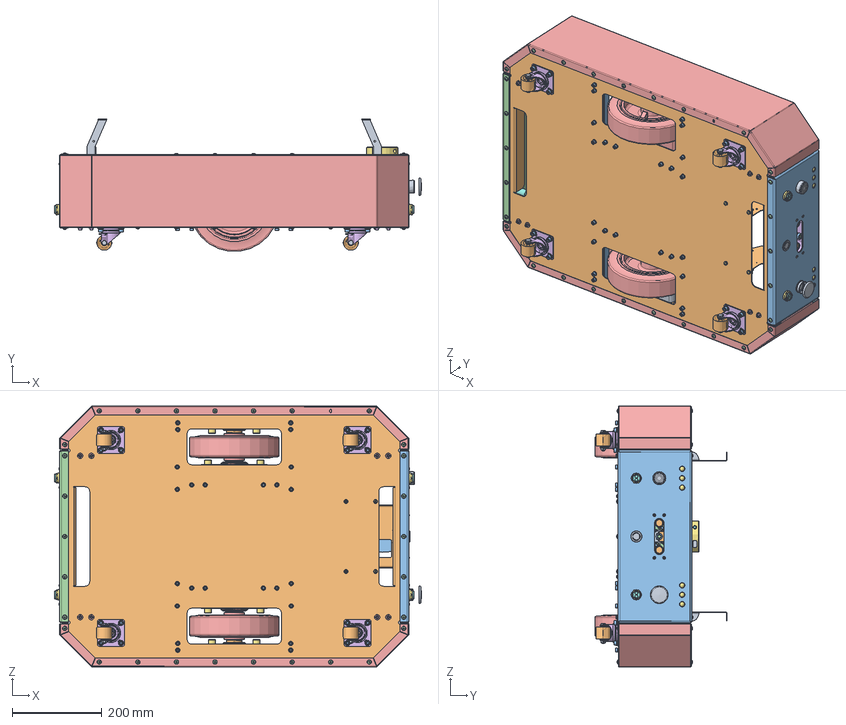
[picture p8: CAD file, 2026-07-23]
Mechanical/Cad/Assembly_steam cleaning robot_BASE.step
818.6 x 295.3 x 582.0 mm
MMP.02.00.00.001 Base_® ã¬®« ç ¨î
Ãàéêà êëåïàëüíà ÿ Ì4_0,5-2 óì. ïîòàé, ñòà ëü_ãáâ.  2 ¬¬ x 33
Ãàéêà êëåïàëüíà ÿ Ì6_0,5-2,5 óì. ïîòàé, ñò àëü_ãáâ.  1,5 ¬¬ x 16
GEVN_200_30H7_G15 x 2
ÐÒ1.00.00.217 Øïîíêà_ ® ã¬®«ç ¨î x 2
Øïîíêà 3-4x4x25 ÃÎÑÒ 23360-78 _® ã¬®«ç ¨î x 2
PT1.00.00.241 Adapter_00 x 2
PT1.00.00.242 Bracket_00 x 2
PT1.00.00.243 Cover_00 x 2
Ïëàòà ìàãíèò íîãî ýíêîäåðà_00 x 2
Âèíò Ì2-6gx8.48 DIN 7985_00 x 8
Ãàéêà M2 DIN 934_00 x 8
Ñåðäå÷íèê BMN-35H _00 x 2
Ìîòîð-ðåäóêòîð Z4 BLD60-24GU ñåðèÿ 80_® ã¬®« ç ¨î x 2
MMP.03.00.00.001 Wheel bracket outer_® ã¬®«ç ¨î x 2
MMP.03.00.00.002 Wheel bracket inner_® ã¬®«ç ¨î x 2
MMP.03.00.00.003 Motor bracket_® ã¬®«ç ¨î x 2
MMP.03.00.00.004 Drive shaft_® ã¬® «ç ¨î x 2
âèíò din 965 (ïîòàé)_ISO 7046-1 - M3 x 12 - Z --- 12C x 4
Âèíò DIN 912 (âí. øåñò.)_DIN 912 M10 x 45 --- 32C x 8
Øàéáà DIN 7980 (ïðóæèíí àÿ)_ ©¡ 10  6402-70 x 8
Øàéáà DIN 125_Washer DIN 125 - A 10.5 x 12
Ãàéêà DIN 934_Hexagon Nut ISO - 4032 - M10 - D - C x 8
Âèíò DIN 912 (âí. øåñò.)_DIN 912 M5 x 20 --- 20C x 18
Øàéáà DIN 7980 (ïðóæèíí àÿ)_ ©¡ 5  6402-70 x 48
Øàéáà DIN 125_Washer DIN 125 - A 5.3 x 27
Âèíò DIN 912 (âí. øåñò.)_DIN 912 M5 x 70 --- 35C x 8
Ãàéêà êëåïàëüíà ÿ Ì5_0,5-2 óì. ïîòàé, ñòà ëü_ãáâ.  2 ¬¬ x 40
Rexnord-UCFL- SUCFL- HCFL- SHCFL-UCFL 205 C-68563_HUB x 2
Rexnord-UCFL- SUCFL- HCFL- SHCFL-UCFL 205 C-68563_BEARING x 2
Rexnord-UCFL- SUCFL- HCFL- SHCFL-UCFL 205 C-68563_NIPPLE x 2
Rexnord-UCFL- SUCFL- HCFL- SHCFL-UCFL 206 C-68439_HUB x 2
Rexnord-UCFL- SUCFL- HCFL- SHCFL-UCFL 206 C-68439_BEARING x 2
Rexnord-UCFL- SUCFL- HCFL- SHCFL-UCFL 206 C-68439_NIPPLE x 2
Ãàéêà DIN 934_Hexagon Nut ISO - 4032 - M3 - D - C x 4
Ãàéêà êëåïàëüíà ÿ Ì4_0,5-2 óì. ïîòàé, ñòà ëü_ãáâ.  1,2 ¬¬ x 24
MMP.05.00.00.001 Support_® ã¬®« ç ¨î x 2
MMP.05.00.00.001 Support_¥àª « ª x 2
MMP.07.00.00.001 Lidar support_® ã¬®«ç ¨î
MMP.00.00.00.001 Front panel_® ã¬® «ç ¨î
MMP.00.00.00.002 Back panel_® ã¬® «ç ¨î
MMP.00.00.00.003 Side panel_® ã¬® «ç ¨î x 2
PT1.00.00.032 Camera upper body_00
âèíò din 966 (ïîëóïîòà é)_ISO 7047 - M3 x 8 - Z --- 8C x 4
âèíò din 967 (ñ áóðò.)_DIN 967 - M3 x 12 - Z --- 12C x 4
Âèíò DIN 7985 (öèë.)_ISO 7045 - M2 x 16 - Z --- 16C x 4
Øàéáà DIN 125_Washer DIN 125 - A 3.2 x 20
Ãàéêà DIN 934_Hexagon Nut ISO - 4032 - M2 - D - C x 4
Øàéáà DIN 7980 (ïðóæèíí àÿ)_ ©¡ 2  6402-70 x 4
Øàéáà DIN 125_Washer DIN 125 - A 2.2 x 4
Âèíò DIN 7985 (öèë.)_ISO 7045 - M2.5 x 6 - Z --- 6C x 4
Âèíò DIN 7985 (öèë.)_ISO 7045 - M4 x 16 - Z --- 16C x 4
Øàéáà DIN 125_Washer DIN 125 - A 4.3 x 4
Øàéáà DIN 7980 (ïðóæèíí àÿ)_ ©¡ 4  6402-70 x 12
Øàéáà DIN 7980 (ïðóæèíí àÿ)_ ©¡ 3  6402-70 x 4
Âèíò DIN 912 (âí. øåñò.)_DIN 912 M6 x 20 --- 20C x 23
âèíò din 967 (ñ áóðò.)_DIN 967 - M4 x 12 - Z --- 12C x 45
øàéáà din 9021 (óâ.)_Wash er DIN 9021 - 4.3 x 8
Âèíò DIN 912 (âí. øåñò.)_DIN 912 M4 x 16 --- 16C x 8
E18-D80NK Äàò÷èê ÈÊ_0 0 x 4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

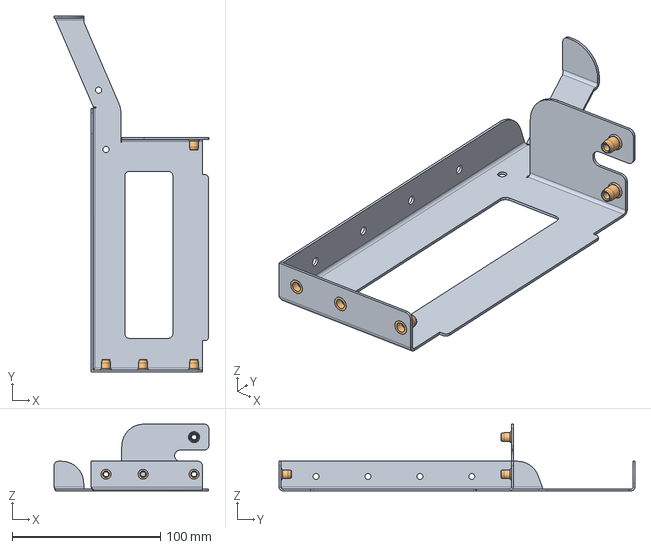
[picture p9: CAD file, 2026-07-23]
Mechanical/Cad/Support assembly_00.step
104.3 x 240.0 x 45.0 mm
MMP.05.00.00.001 Support_¥àª « ª
Ãàéêà êëåïàëüíà ÿ Ì4_0,5-2 óì. ïîòàé, ñòà ëü_ãáâ.  1,2 ¬¬ x 5

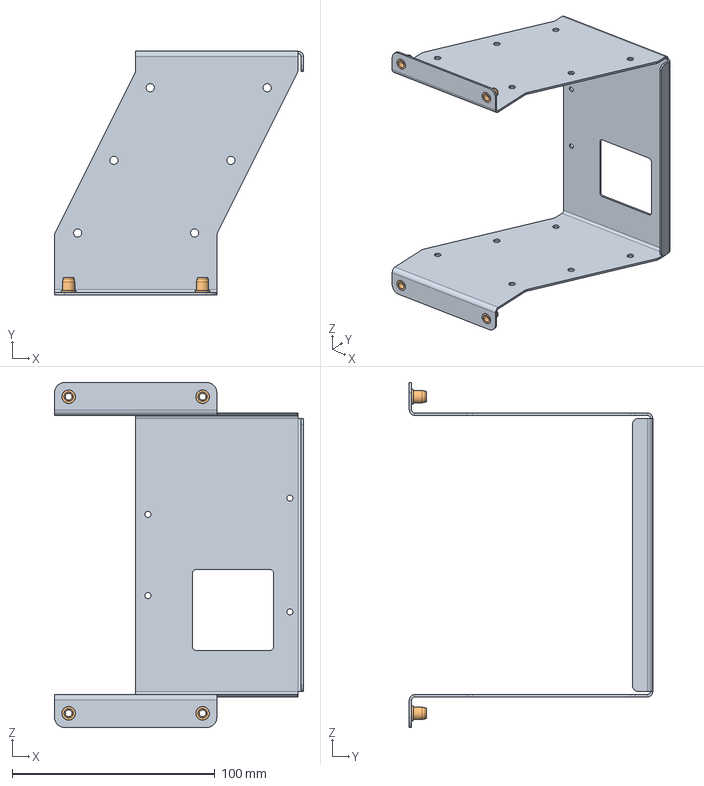
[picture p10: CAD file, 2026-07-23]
Mechanical/Cad/Lidar support assembly.step
122.7 x 120.0 x 170.0 mm
MMP.07.00.00.001 Lidar support_® ã¬® «ç ¨î
Ãàéêà êëåïàëüíà ÿ Ì4_0,5-2 óì. ïîòàé, ñòà ëü_ãáâ.  1,2 ¬¬ x 4

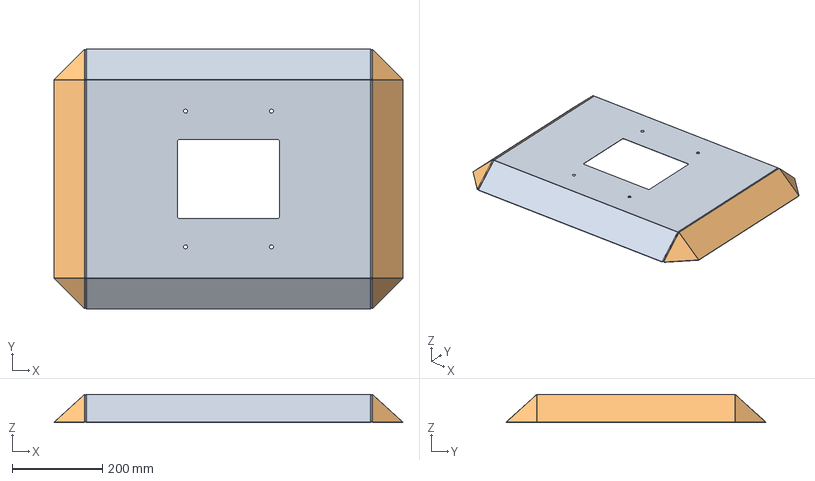
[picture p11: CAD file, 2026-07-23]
Mechanical/Cad/Cover assembly.step
771.6 x 575.6 x 63.0 mm
MMP.01.00.00.001 Cover_00
MMP.01.00.00.002 Cover flange_00 x 2
Âèíò DIN 7985 (öèë.)_ISO 7045 - M3 x 8 - Z --- 8C x 10
Ãàéêà DIN 934_Hexagon Nut ISO - 403 2 - M3 - D - C x 10
Øàéáà DIN 125_Washer DIN 125 - A 3. 2 x 20
Øàéáà DIN 7980 (ïðóæèíí àÿ)_ ©¡ 3  6402-70 x 10

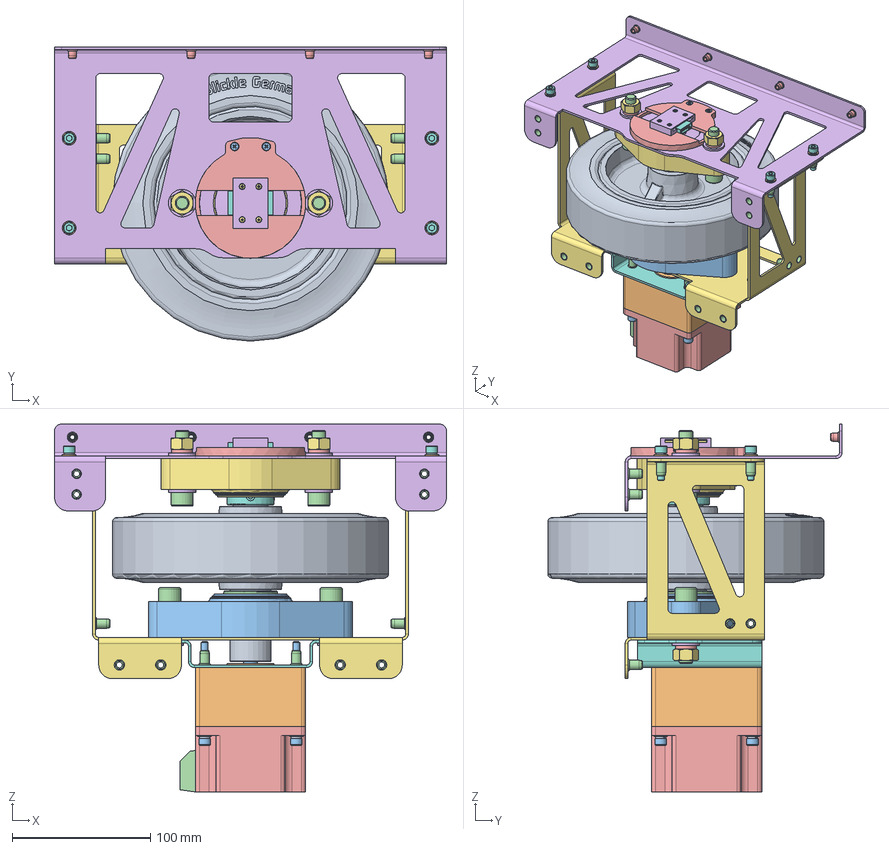
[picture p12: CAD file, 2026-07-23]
Mechanical/Cad/Wheel assembly.step
284.0 x 213.2 x 266.5 mm
GEVN_200_30H7_G15
ÐÒ1.00.00.217 Øïîíêà_ ® ã¬®«ç ¨î
Øïîíêà 3-4x4x25 ÃÎÑÒ 23360-78 _® ã¬®«ç ¨î
ÐÒ1.00.00.241 Ïåðåõîä íèê_00
ÐÒ1.00.00.242 Êðîíøòå éí_00
ÐÒ1.00.00.243 Êðûøêà_0 0
Ïëàòà ìàãíèò íîãî ýíêîäåðà_00
Âèíò Ì2-6gx8.48 DIN 7985_00 x 4
Ãàéêà M2 DIN 934_00 x 4
Ñåðäå÷íèê BMN-35H_ 00
Ìîòîð-ðåäóêòîð Z4 BLD60-24GU ñåðèÿ 80_® ã¬®« ç ¨î
MMP.03.00.00.001 Wheel bracket outer_® ã¬®«ç ¨î
MMP.03.00.00.002 Wheel bracket inner_® ã¬®«ç ¨î
MMP.03.00.00.003 Motor bracket_® ã¬® «ç ¨î
MMP.03.00.00.004 Drive shaft_® ã¬® «ç ¨î
Ãàéêà DIN 934_Hexagon Nut ISO - 40 32 - M3 - D - C x 2
Âèíò DIN 965 (ïîòàé)_ISO 7046-1 - M3 x 12 - Z --- 12C x 2
Âèíò DIN 912 (âí. øåñò.)_DIN 912 M10 x 45 --- 32C x 4
Øàéáà DIN 7980 (ïðóæèíí àÿ)_ ©¡ 10  6402-70 x 4
Øàéáà DIN 125_Washer DIN 125 - A 1 0.5 x 6
Ãàéêà DIN 934_Hexagon Nut ISO - 4032 - M10 - D - C x 4
Âèíò DIN 912 (âí. øåñò.)_DIN 912 M5 x 20 --- 20C x 4
Øàéáà DIN 7980 (ïðóæèíí àÿ)_ ©¡ 5  6402-70 x 8
Øàéáà DIN 125_Washer DIN 125 - A 5. 3 x 8
Âèíò DIN 912 (âí. øåñò.)_DIN 912 M5 x 70 --- 35C x 4
Ãàéêà êëåïàëüíà ÿ Ì5_0,5-2 óì. ïîòàé, ñòà ëü_ãáâ.  2 ¬¬ x 20
Ãàéêà êëåïàëüíà ÿ Ì4_0,5-2 óì. ïîòàé, ñòà ëü_ãáâ.  2 ¬¬ x 4
Rexnord-UCFL- SUCFL- HCFL- SHCFL-UCFL 205 C-68563_HUB
Rexnord-UCFL- SUCFL- HCFL- SHCFL-UCFL 205 C-68563_BEARING
Rexnord-UCFL- SUCFL- HCFL- SHCFL-UCFL 205 C-68563_NIPPLE
Rexnord-UCFL- SUCFL- HCFL- SHCFL-UCFL 206 C-68439_HUB
Rexnord-UCFL- SUCFL- HCFL- SHCFL-UCFL 206 C-68439_BEARING
Rexnord-UCFL- SUCFL- HCFL- SHCFL-UCFL 206 C-68439_NIPPLE

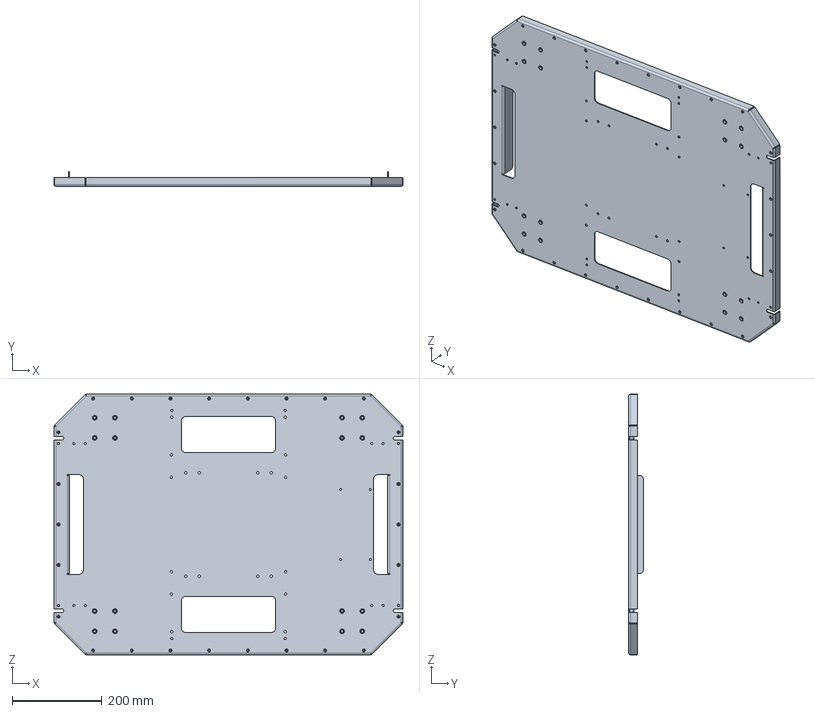
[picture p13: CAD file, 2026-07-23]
Mechanical/Cad/Base assembly.step
776.0 x 33.2 x 580.0 mm
MMP.02.00.00.001 Base_® ã¬®«ç ¨î
Ãàéêà êëåïàëüíà ÿ Ì4_0,5-2 óì. ïîòàé, ñòà ëü_ãáâ.  2 ¬¬ x 26
Ãàéêà êëåïàëüíà ÿ Ì6_0,5-2,5 óì. ïîòàé, ñò àëü_ãáâ.  1,5 ¬¬ x 16

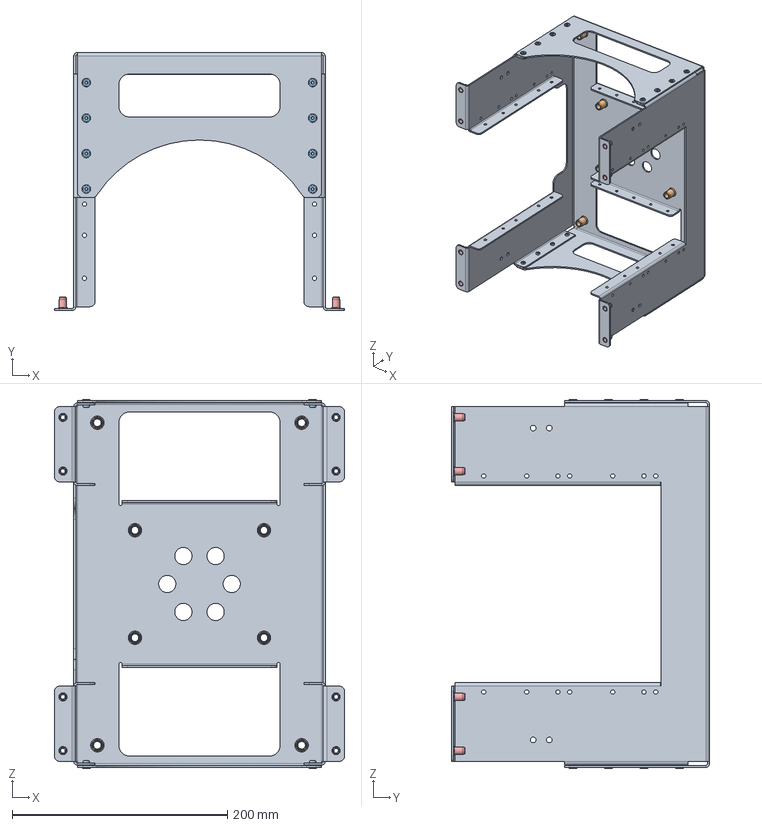
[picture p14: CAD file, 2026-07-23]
Mechanical/Cad/Center bracket assembly.step
270.0 x 240.0 x 343.2 mm
MMP.04.00.00.001 Center bracket_® ã¬®«ç ¨î
Ãàéêà êëåïàëüíà ÿ Ì8_0,5-2,5 óì. ïîòàé, ñò àëü_ãáâ.  2 ¬¬ x 8
Çàêë¸ïêà âûòÿæí àÿ 4,0 DIN 7337_ 4,1 x 16
Ãàéêà êëåïàëüíà ÿ Ì5_0,5-2 óì. ïîòàé, ñòà ëü_ãáâ.  2 ¬¬ x 8

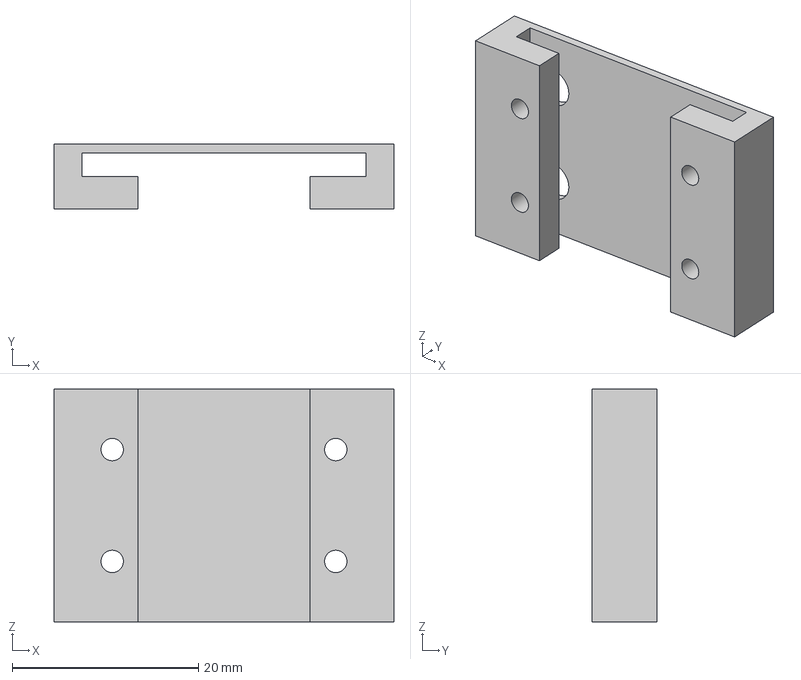
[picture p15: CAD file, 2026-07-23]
Mechanical/Cad/Side_Cover.step
36.5 x 7.00 x 25.0 mm

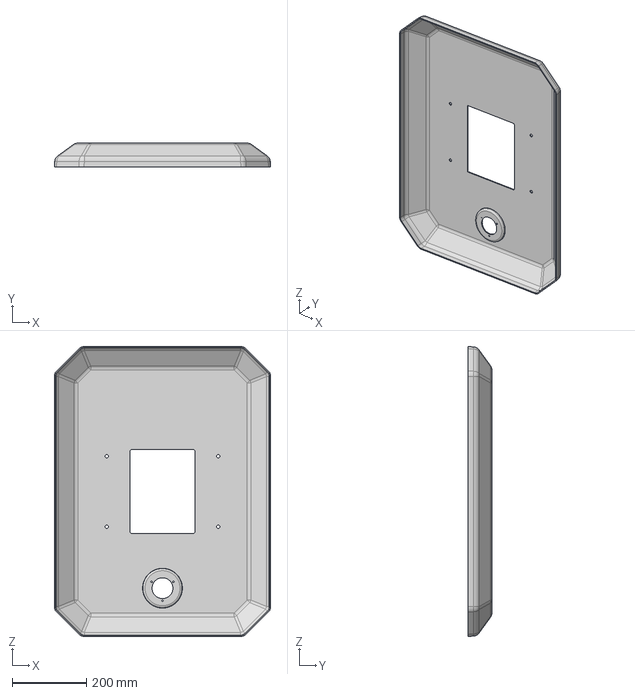
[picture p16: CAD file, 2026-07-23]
Mechanical/Cad/Plastic cover.step
582.0 x 64.0 x 780.0 mm

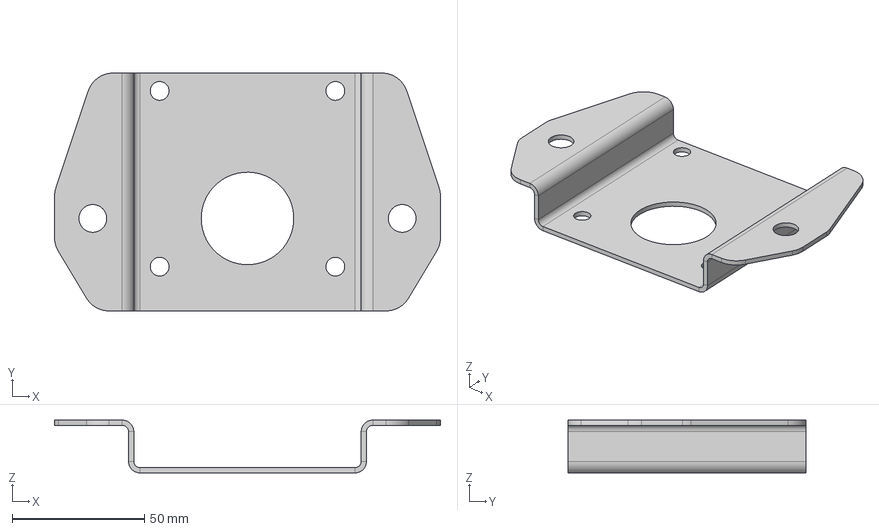
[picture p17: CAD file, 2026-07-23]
Mechanical/Cad/Motor bracket.step
146.0 x 90.0 x 20.0 mm

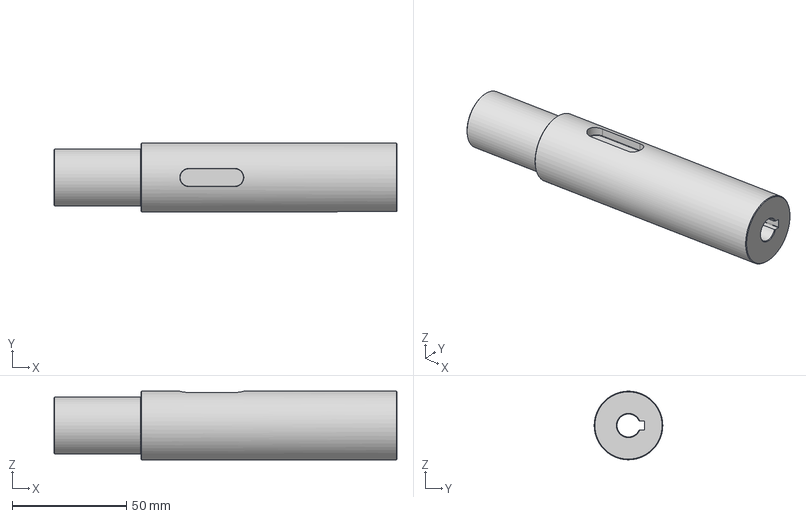
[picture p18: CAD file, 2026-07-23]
Mechanical/Cad/Drive shaft.step
150.0 x 30.0 x 30.0 mm

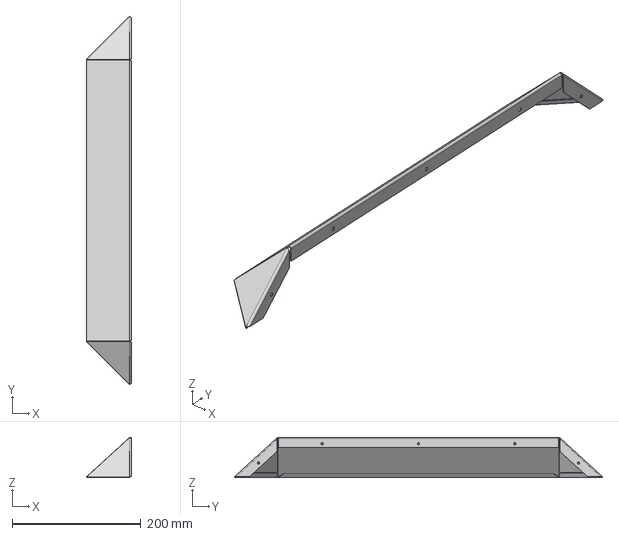
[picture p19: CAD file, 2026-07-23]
Mechanical/Cad/Cover flange.step
70.6 x 572.7 x 63.0 mm

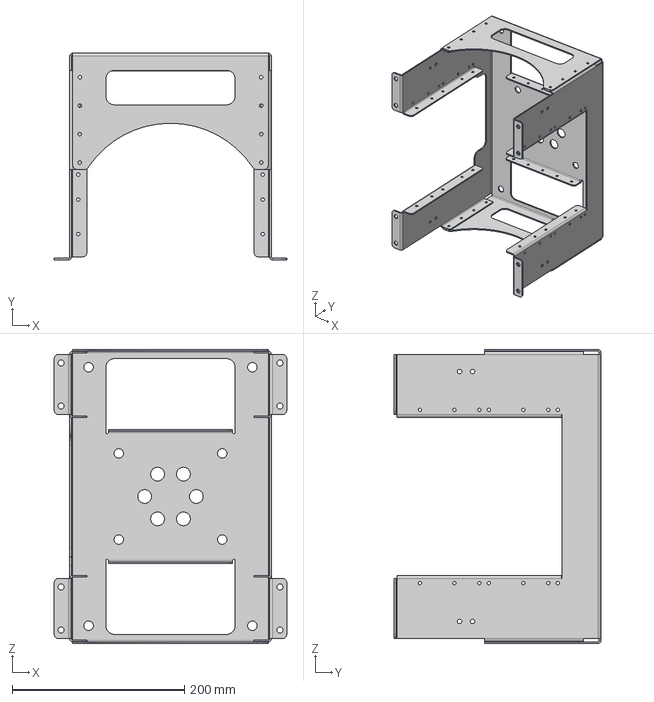
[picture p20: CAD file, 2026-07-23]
Mechanical/Cad/Center bracket_001.step
270.0 x 240.0 x 341.2 mm

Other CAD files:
Mechanical/Cad/Support assembly_01.step
Mechanical/Cad/full_assembly_steam cleaning robot_BASE.step
Mechanical/Cad/Bracket.step
Mechanical/Cad/Back panel.step
Mechanical/Cad/Base.step
Mechanical/Cad/Camera upper body.step
Mechanical/Cad/Cover.step
Mechanical/Cad/Front panel.f3d
Mechanical/Cad/Lidar support.step
Mechanical/Cad/Magnetic encoder.step
Mechanical/Cad/Power_Adapter.step
Mechanical/Cad/Side panel.step
Mechanical/Cad/Support.step
Mechanical/Cad/Wheel bracket inner.step
Mechanical/Cad/Wheel bracket outer.step
datasheets/ZLTech/wheel_ZLLG80ASM250/ZLLG80ASM250-L V3.0single-shaft.SLDASM
datasheets/ZLTech/wheel_ZLLG80ASM250/ZLLG80ASM250-L V3.0single-shaft.dwg

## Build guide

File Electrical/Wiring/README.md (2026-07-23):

# Wiring & Arduino MEGA pinout

*Last updated: 2026-07-23.*

Convention: **MOTOR1 = LEFT wheel, MOTOR2 = RIGHT wheel.** Logic level **3.3 V**.

> **Verification status (2026-06-19):** full wiring/component audit done. Physically verified —
> **drivers + motors** (ZBLD C20-120L2R + ZD Z4BLD60-24GN-30S, both drivers identical), **encoders**
> (AS5040; the 5 V→~4 V overvoltage was **fixed → now 3.3 V**, see [encoders.md](../sensors/encoders.md)), **IMU**
> (MPU-6500, SDA18/SCL19, 3.3 V, 0x68), **Teensy = 4.0** (i.MX RT1062), **power/24 V** (no fuse / no
> battery cut-off 
> Still to read (completeness): LiDAR model sticker, DC-DC model, AC/DC converter, gearbox suffix.
> (Pi RAM confirmed **8 GB**, 2026-07-06 — see [raspberry-pi.md](../computing/raspberry-pi.md).)

The complete power-and-signal wiring is shown in the harness diagram below; the sections that
follow give the exact pin/terminal tables behind it.

Figure 1 — wiring harness: 24 V power and 3.3 V logic domains, every signal link

## Arduino MEGA pin assignment

| Function | Pin | Notes |
|---|---|---|
| **IMU** SDA | 18 | I²C data (MPU6500 @ 0x68) |
| **IMU** SCL | 19 | I²C clock |
| **Encoder LEFT (M1)** A | 14 | quadrature |
| **Encoder LEFT (M1)** B | 15 | quadrature |
| **Encoder RIGHT (M2)** A | 11 | quadrature |
| **Encoder RIGHT (M2)** B | 12 | quadrature |
| **Motor LEFT (M1)** PWM | 1 | → driver `VAR/AI2` (speed) |
| **Motor LEFT (M1)** IN_A / FWD | 20 | → driver `FWD/DI1` |
| **Motor LEFT (M1)** IN_B / REV | 21 | → driver `REV/DI2` |
| **Motor RIGHT (M2)** PWM | 5 | → driver `VAR/AI2` (speed) |
| **Motor RIGHT (M2)** IN_A / FWD | 6 | → driver `FWD/DI1` |
| **Motor RIGHT (M2)** IN_B / REV | 8 | → driver `REV/DI2` |
| Debug LED | 13 | init/status (3 blinks = init failure) |
| micro-ROS | USB | native serial, 115200 baud |

> These values are the firmware's pin configuration — see `openamr-platform-fw`.
> Note: `MOTOR1_PWM` is pin **1** (pin 21 is **not** a PWM pin on the Teensy 4.x — a common upstream pitfall).

## Driver wiring — ZBLD C20-120L2R (VERIFIED 2026-06-19)

Both drivers are wired **identically** (only the Teensy pins differ). The signal terminal block has 12
positions; **exactly 4 are connected** per driver (read off the board: `x`=wired, `o`=empty, from FWD):

```
FWD/DI1  REV/DI2  JOG/DI3  CLR/DI4  BRK/DI5  COM  VAR/AI2  +5V  ERR/DO1  SPD/DO2  A+  B-
   x        x        o        o        o      x      x      o      o        o     o   (o)
```

| Driver terminal | Role | ← Teensy LEFT (M1) | ← Teensy RIGHT (M2) |
|---|---|---|---|
| `VAR/AI2` | speed setpoint, analog **0–5 V** (Teensy PWM @3 kHz, filtered) | PWM **1** | PWM **5** |
| `FWD/DI1` | forward direction (digital) | IN_A **20** | IN_A **6** |
| `REV/DI2` | reverse direction (digital) | IN_B **21** | IN_B **8** |
| `COM` | **common ground — mandatory** | GND | GND |

The driver's connected terminals and their Teensy links are shown below.

Figure 3 — ZBLD.C20-120L2R driver connections: the 12-position signal block (only terminals 1/2/6/7 wired), 24 V power, and the 8-pin motor Molex

Unused: `JOG/DI3`, `CLR/DI4`, `BRK/DI5` (brake), `+5V`, `ERR/DO1` (no fault read-back), `SPD/DO2`
(no speed feedback to the Teensy), `A+/B−` (RS485 not used). Speed/gain is set by the on-board **VAR/AI1**
pot + **ACC/DEC** ramp pot (see [motors-drivers.md](../motor_control/motors-drivers.md)).

> ⚠️ The Teensy uses the `USE_GENERIC_2_IN_MOTOR_DRIVER` profile (PWM + INA + INB). On this BLDC driver
> that maps cleanly: PWM→speed (`VAR/AI2`), INA→`FWD/DI1`, INB→`REV/DI2`. The driver does its own
> commutation from the Hall sensors — the Teensy never sees U/V/W.

### DIP switches (config applied 2026-06-19, identical both drivers)
| SW1 | SW2 | SW3 | SW4 | SW5 | SW6 |
|---|---|---|---|---|---|
| **OFF** | **ON** | OFF | **ON** | **ON** | OFF |

The switch positions are shown below.

Figure 4 — driver DIP switches SW1..SW6 in the applied configuration (OFF·ON·OFF·ON·ON·OFF)

- **SW1 = OFF → open loop** (driver is a power stage; the **Teensy PID** is the sole regulator — best
  for this robot, removes the double loop). *Was ON (closed loop); changed 2026-06-19.* Validated: smooth.
- **SW2 = ON → speed source = AI2** (the external 0–5 V input where our PWM arrives). Must stay ON.
- **SW4 = ON, SW5 = ON → 5 pole pairs** (motor is P=5). *Was OFF/OFF (=2 pp, wrong); corrected.*
  Irrelevant in open loop but set correctly for future closed-loop use.
- **SW6 = OFF** (no RS485). See the full rationale in [motors-drivers.md](../motor_control/motors-drivers.md).
- ⚠️ With SW2=ON (AI2 source), the **VAR pot is inert** for balancing — speed comes from the PWM, not the
  pot. The residual ~9 % open-loop L/R asymmetry is handled by the Teensy PID (→ ~0.2 %).

## Motor wiring (per motor) — VERIFIED 2026-06-19
Driver **power**: `V+ / V− = 24 V DC` (大 screw terminals, bottom-right, `电源DC24V`), fused.

> ⚠️ **DC power wire colours on THIS robot** (confirmed 2026-06-18, counter-intuitive — AC-style colours on
> a DC bus): **brown = + (V+, i.e. the DC "red")**, **blue = − (V−, i.e. the DC "black")**. Colour is only a
> presumption — **verify with a multimeter** before connecting a 24 V lead. See [power.md](../power_distribution/power.md).

Driver **motor connector** (white Molex, 8 pins):

| `U` | `V` | `W` | `Hu` | `Hv` | `Hw` | `Vcc` | `0V` |
|---|---|---|---|---|---|---|---|
| phase U | phase V | phase W | Hall U | Hall V | Hall W | +5 V (Hall supply) | GND (Hall) |

> 🔧 **Left-wheel blocker:** the left signal wiring (4 terminals above) is **proven healthy**, so the
> intermittent left wheel is NOT here — it's on the **24 V power (V+/V−)** or the **motor connector**
> (a phase or the Molex). That's where to chase the faux-contact (continuity test while flexing). See
> the `openamr-platform-sw` troubleshooting doc (`docs/troubleshooting/diagnostics.md` in that repo) and the `amr-left-wheel-faux-contact` memo.

## Grounding
All grounds must be common: **Teensy GND ↔ driver COM**. A floating COM was a real source of noise
concern (see the `openamr-platform-sw` troubleshooting doc (`docs/troubleshooting/diagnostics.md` in that repo)).

## ASCII map
```
                 Arduino MEGA (3.3V)
   IMU  ── SDA18/SCL19 ───────────────► MPU6500 (I2C 0x68)
   ENC L ── A14/B15 ──────────────────► encoder LEFT
   ENC R ── A11/B12 ──────────────────► encoder RIGHT
   M1   ── PWM1 / IN20 / IN21 ────────► driver LEFT  ── U/V/W ─► motor LEFT
   M2   ── PWM5 / IN6 / IN8 ──────────► driver RIGHT ── U/V/W ─► motor RIGHT
   USB ───────────────────────────────► Raspberry Pi (micro-ROS 115200)
   GND ───────────────────────────────► COM of both drivers (common)

```

# Schematic to understand how Emergency switch and reset button works.

Power_connection_AMR_1

## Chinese clone (~ HKD 10–HKD 50):
XB2-BS542 — same Ø22/Ø40 form factor, 1NC, twist release, 10 A Ith, IP65, IEC 60947-5-1, but no e-stop-specific certification. Fine for prototypes and internal testing.
→ https://www.amazon.com/XB2-BS542-Emergency-Button-Switch-pushbutton/dp/B07Y7KZDSH
→ direct from manufacturer, ~$1/pc: https://www.finglai.com/products/switches/push-buttons/DIA22-XB2-B/XB2-BS542.html
LAY37 is the same class, usually sold as NO+NC: https://www.amazon.com/LAY37-Mushroom-Emergency-Button-Switch/dp/B07DL333VL [eBay](https://www.ebay.com/itm/356714450971)[Electric-b2c](https://www.electric-b2c.com/products/button-switch-self-reset-xb2-small-mushroom-head-emergency-stop-22mm-knob-key-start-inching-power-on-xb2-bs542-xb2-ba31-xb2-ba4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)

Reminder: contacts are ~3 A DC-13 at 24 V, so for the Robot battery bus, break a contactor coil with the NC contacts rather than the full motor current.

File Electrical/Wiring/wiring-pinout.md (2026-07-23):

# Wiring & Teensy 4.0 pinout

*Last updated: 2026-06-19.*

Convention: **MOTOR1 = LEFT wheel, MOTOR2 = RIGHT wheel.** Logic level **3.3 V**.

> **Verification status (2026-06-19):** full wiring/component audit done. Physically verified —
> **drivers + motors** (ZBLD C20-120L2R + ZD Z4BLD60-24GN-30S, both drivers identical), **encoders**
> (AS5040; the 5 V→~4 V overvoltage was **fixed → now 3.3 V**, see [encoders.md](../sensors/encoders.md)), **IMU**
> (MPU-6500, SDA18/SCL19, 3.3 V, 0x68), **Teensy = 4.0** (i.MX RT1062), **power/24 V** (no fuse / no
> battery cut-off — see [power.md](../power_distribution/power.md)). Component list + datasheets: [components-bom.md](../../manufacturing/bom/components-bom.md).
> Still to read (completeness): LiDAR model sticker, DC-DC model, AC/DC converter, gearbox suffix.
> (Pi RAM confirmed **8 GB**, 2026-07-06 — see [raspberry-pi.md](../computing/raspberry-pi.md).)

The complete power-and-signal wiring is shown in the harness diagram below; the sections that
follow give the exact pin/terminal tables behind it.

Figure 1 — OpenAMRobot wiring harness: 24 V power and 3.3 V logic domains, every signal link

## Teensy 4.0 pin assignment

| Function | Pin | Notes |
|---|---|---|
| **IMU** SDA | 18 | I²C data (MPU6500 @ 0x68) |
| **IMU** SCL | 19 | I²C clock |
| **Encoder LEFT (M1)** A | 14 | quadrature |
| **Encoder LEFT (M1)** B | 15 | quadrature |
| **Encoder RIGHT (M2)** A | 11 | quadrature |
| **Encoder RIGHT (M2)** B | 12 | quadrature |
| **Motor LEFT (M1)** PWM | 1 | → driver `VAR/AI2` (speed) |
| **Motor LEFT (M1)** IN_A / FWD | 20 | → driver `FWD/DI1` |
| **Motor LEFT (M1)** IN_B / REV | 21 | → driver `REV/DI2` |
| **Motor RIGHT (M2)** PWM | 5 | → driver `VAR/AI2` (speed) |
| **Motor RIGHT (M2)** IN_A / FWD | 6 | → driver `FWD/DI1` |
| **Motor RIGHT (M2)** IN_B / REV | 8 | → driver `REV/DI2` |
| Debug LED | 13 | init/status (3 blinks = init failure) |
| micro-ROS | USB | native serial, 115200 baud |

> These values are the firmware's pin configuration — see `openamr-platform-fw`.
> Note: `MOTOR1_PWM` is pin **1** (pin 21 is **not** a PWM pin on the Teensy 4.x — a common upstream pitfall).

The same assignment is shown as a physical pin map below.

Figure 2 — Teensy 4.0 pin map: every used pin labeled by function

## Driver wiring — ZBLD C20-120L2R (VERIFIED 2026-06-19)

Both drivers are wired **identically** (only the Teensy pins differ). The signal terminal block has 12
positions; **exactly 4 are connected** per driver (read off the board: `x`=wired, `o`=empty, from FWD):

```
FWD/DI1  REV/DI2  JOG/DI3  CLR/DI4  BRK/DI5  COM  VAR/AI2  +5V  ERR/DO1  SPD/DO2  A+  B-
   x        x        o        o        o      x      x      o      o        o     o   (o)
```

| Driver terminal | Role | ← Teensy LEFT (M1) | ← Teensy RIGHT (M2) |
|---|---|---|---|
| `VAR/AI2` | speed setpoint, analog **0–5 V** (Teensy PWM @3 kHz, filtered) | PWM **1** | PWM **5** |
| `FWD/DI1` | forward direction (digital) | IN_A **20** | IN_A **6** |
| `REV/DI2` | reverse direction (digital) | IN_B **21** | IN_B **8** |
| `COM` | **common ground — mandatory** | GND | GND |

The driver's connected terminals and their Teensy links are shown below.

Figure 3 — ZBLD.C20-120L2R driver connections: the 12-position signal block (only terminals 1/2/6/7 wired), 24 V power, and the 8-pin motor Molex

Unused: `JOG/DI3`, `CLR/DI4`, `BRK/DI5` (brake), `+5V`, `ERR/DO1` (no fault read-back), `SPD/DO2`
(no speed feedback to the Teensy), `A+/B−` (RS485 not used). Speed/gain is set by the on-board **VAR/AI1**
pot + **ACC/DEC** ramp pot (see [motors-drivers.md](../motor_control/motors-drivers.md)).

> ⚠️ The Teensy uses the `USE_GENERIC_2_IN_MOTOR_DRIVER` profile (PWM + INA + INB). On this BLDC driver
> that maps cleanly: PWM→speed (`VAR/AI2`), INA→`FWD/DI1`, INB→`REV/DI2`. The driver does its own
> commutation from the Hall sensors — the Teensy never sees U/V/W.

### DIP switches (config applied 2026-06-19, identical both drivers)
| SW1 | SW2 | SW3 | SW4 | SW5 | SW6 |
|---|---|---|---|---|---|
| **OFF** | **ON** | OFF | **ON** | **ON** | OFF |

The switch positions are shown below.

Figure 4 — driver DIP switches SW1..SW6 in the applied configuration (OFF·ON·OFF·ON·ON·OFF)

- **SW1 = OFF → open loop** (driver is a power stage; the **Teensy PID** is the sole regulator — best
  for this robot, removes the double loop). *Was ON (closed loop); changed 2026-06-19.* Validated: smooth.
- **SW2 = ON → speed source = AI2** (the external 0–5 V input where our PWM arrives). Must stay ON.
- **SW4 = ON, SW5 = ON → 5 pole pairs** (motor is P=5). *Was OFF/OFF (=2 pp, wrong); corrected.*
  Irrelevant in open loop but set correctly for future closed-loop use.
- **SW6 = OFF** (no RS485). See the full rationale in [motors-drivers.md](../motor_control/motors-drivers.md).
- ⚠️ With SW2=ON (AI2 source), the **VAR pot is inert** for balancing — speed comes from the PWM, not the
  pot. The residual ~9 % open-loop L/R asymmetry is handled by the Teensy PID (→ ~0.2 %).

## Motor wiring (per motor) — VERIFIED 2026-06-19
Driver **power**: `V+ / V− = 24 V DC` (大 screw terminals, bottom-right, `电源DC24V`), fused.

> ⚠️ **DC power wire colours on THIS robot** (confirmed 2026-06-18, counter-intuitive — AC-style colours on
> a DC bus): **brown = + (V+, i.e. the DC "red")**, **blue = − (V−, i.e. the DC "black")**. Colour is only a
> presumption — **verify with a multimeter** before connecting a 24 V lead. See [power.md](../power_distribution/power.md).

Driver **motor connector** (white Molex, 8 pins):

| `U` | `V` | `W` | `Hu` | `Hv` | `Hw` | `Vcc` | `0V` |
|---|---|---|---|---|---|---|---|
| phase U | phase V | phase W | Hall U | Hall V | Hall W | +5 V (Hall supply) | GND (Hall) |

> 🔧 **Left-wheel blocker:** the left signal wiring (4 terminals above) is **proven healthy**, so the
> intermittent left wheel is NOT here — it's on the **24 V power (V+/V−)** or the **motor connector**
> (a phase or the Molex). That's where to chase the faux-contact (continuity test while flexing). See
> the `openamr-platform-sw` troubleshooting doc (`docs/troubleshooting/diagnostics.md` in that repo) and the `amr-left-wheel-faux-contact` memo.

## Grounding
All grounds must be common: **Teensy GND ↔ driver COM**. A floating COM was a real source of noise
concern (see the `openamr-platform-sw` troubleshooting doc (`docs/troubleshooting/diagnostics.md` in that repo)).

## ASCII map
```
                 Teensy 4.0 (3.3V)
   IMU  ── SDA18/SCL19 ───────────────► MPU6500 (I2C 0x68)
   ENC L ── A14/B15 ──────────────────► encoder LEFT
   ENC R ── A11/B12 ──────────────────► encoder RIGHT
   M1   ── PWM1 / IN20 / IN21 ────────► driver LEFT  ── U/V/W ─► motor LEFT
   M2   ── PWM5 / IN6 / IN8 ──────────► driver RIGHT ── U/V/W ─► motor RIGHT
   USB ───────────────────────────────► Raspberry Pi (micro-ROS 115200)
   GND ───────────────────────────────► COM of both drivers (common)

```

# Schematic to understand how Emergency switch and reset button works.

Power_connection_AMR_1

### [E-Stop button and Power distribution - OpenAMRobot discussions](https://github.com/orgs/openAMRobot/discussions/6)

## Schneider (genuine, ~€20–35):
Harmony XB4-BS542 — Ø22 mm mount, red Ø40 mm mushroom, twist-to-release, metal bezel, 1NC (add a ZBE-102 block for a second NC channel). Certified positive-opening contacts per IEC 60947-5-5 — the one to use for anything CE-facing.
→ https://www.se.com/ww/en/product/XB4BS542/
Plastic-bezel equivalent: XB5-AS542, same page structure at se.com.

## Chinese clone (~€1–5):
XB2-BS542 — same Ø22/Ø40 form factor, 1NC, twist release, 10 A Ith, IP65, IEC 60947-5-1, but no e-stop-specific certification. Fine for prototypes and internal testing.
→ https://www.amazon.com/XB2-BS542-Emergency-Button-Switch-pushbutton/dp/B07Y7KZDSH
→ direct from manufacturer, ~$1/pc: https://www.finglai.com/products/switches/push-buttons/DIA22-XB2-B/XB2-BS542.html
LAY37 is the same class, usually sold as NO+NC: https://www.amazon.com/LAY37-Mushroom-Emergency-Button-Switch/dp/B07DL333VL [eBay](https://www.ebay.com/itm/356714450971)[Electric-b2c](https://www.electric-b2c.com/products/button-switch-self-reset-xb2-small-mushroom-head-emergency-stop-22mm-knob-key-start-inching-power-on-xb2-bs542-xb2-ba31-xb2-ba4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)

Reminder: contacts are ~3 A DC-13 at 24 V, so for the OpenAMRobot battery bus, break a contactor coil with the NC contacts rather than the full motor current.

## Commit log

2026-07-22 Create Arduino Mega
2026-07-22 Add camera documentation for Pi Camera Module 3 NoIR
2026-07-22 Create arduino gvh
2026-07-23 Update and rename wiring-pinout.md to README.md
2026-07-23 Update and rename power.md to README.md
2026-07-23 Fix image filename for Mobility Full Assembly
